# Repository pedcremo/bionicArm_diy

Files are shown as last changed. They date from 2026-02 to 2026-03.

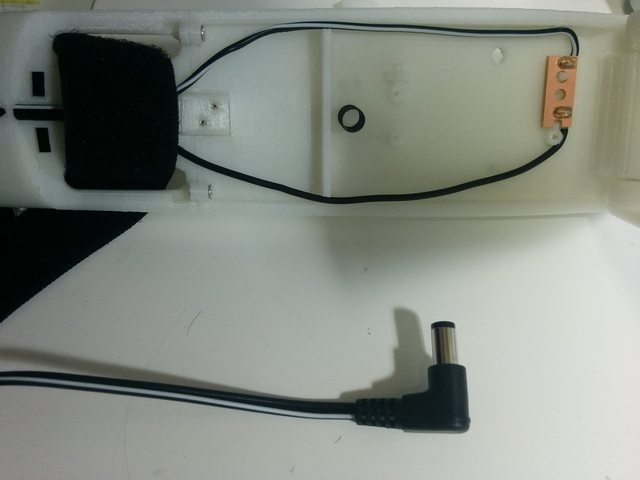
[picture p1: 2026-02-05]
HACKberry_original_project/HACKberry_circuit/BatteryBoard_v1/150908BatteryBoardTemp02.jpg

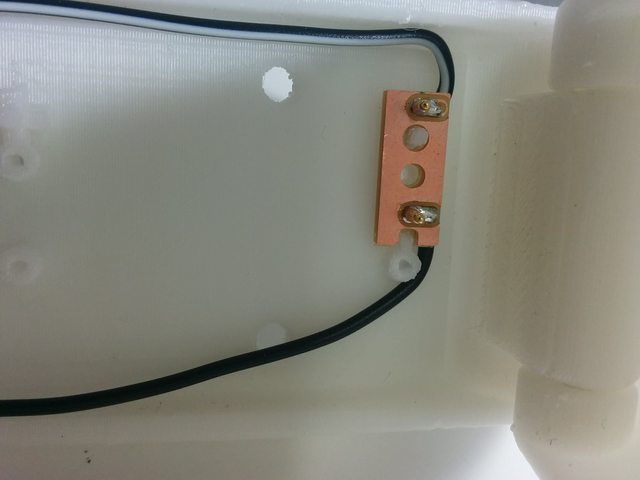
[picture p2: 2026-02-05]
HACKberry_original_project/HACKberry_circuit/BatteryBoard_v1/150908BatteryBoardTemp01.jpg

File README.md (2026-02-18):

At the moment we can explore two options. Brunel and hackberry arm. A britain and japanesse projects respectively. 
Brunel seems more a hand and it looks like more robust and handy. Moreover the company releasing their design sells commercial bionic orthoprotesic arms. 

# Brunel 2.0 hand openbionicslabs
In this repository the most promising device seems brunei hand 
https://github.com/Open-Bionics

# Hackberry arm
We want to upgrade HACKberry bionic arm to the next level. https://github.com/mission-arm/HACKberry

We want to use most of the 3D parts but redefining the sensoric, electronics and software used in the original project

# EMG sensors
More or equally important than hand is the signals produced by the sensors. Preferably EMG ones. We have several options. 
- https://wearables.com/products/myo
- https://psylink.me/
- https://www.btsbioengineering.com/products/freeemg/
- https://myoware.com/

# other options

https://hub.e-nable.org/s/e-nable-devices/wiki/Unlimbited+Arm+v2.1

In the meanwhile could be interesting to get a try in a pure mechanical open prothesic arm. Take a look at https://www.makerhand.com/

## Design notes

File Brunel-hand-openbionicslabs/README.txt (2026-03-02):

Brunel Hand 2.0 by openbionics on Thingiverse: 
https://www.thingiverse.com/thing:3000641

Summary:
The Brunel Hand 2.0 is an advanced, lightweight and precise 
robotic hand for researchers. With a low cost and open source 
design, this fully articulated device is primed to revolutionise
 the future of robotics research. All over the world, 
 university researchers and roboticists are using the Brunel 
 Hand 2.0. It has nine degrees of freedom, four degrees of 
 articulation, and can be programmed using the Arduino 
 programming environment.The Brunel Hand 2.0 is compatible with 
 robot arms and perfect for anyone doing a project with robotic 
 hands or wants a neat, light, and functional robotic hand for 
 use with a humanoid robot. 
 
 It's an excellent platform for 
 research into prosthetics, object grasping and many 
 human-robot-interaction applications.3D Printed Components:
 All of the components required for a right hand start with 'RH' 
 and the components for a left hand start with 'LH'. 
 Assembly instructions are available in 'Thing Files'.
 
 Non-3D Printed Components:
 
 1x - Chestnut PCB 
 https://openbionicslabs.com/shop/chestnut-board

 3x - PQ12 Motors 
 https://openbionicslabs.com/shop/pq12-63-12-p
 
 3x - Conical Springs 
 https://www.assocspring.co.uk/conical-springs/A0600-029-1250-S
 
 8x - Finger Extension Springs 
 http://www.flexosprings.com/search-products?sku=ac2305
 
 1x - Thumb Extension Spring 
 http://www.flexosprings.com/search-products?sku=AD2505
 
 11x - 3x10mm Dowel Pins 
 http://www.boneham.co.uk/Products/dowel-pins/metric-iso-8734b-parallel-dowel-pins
 
 2x - M2x5mm Torx Countersunk Screws 
 https://www.accu.co.uk/en/hexalobular-countersunk-screws/7537-SHK-M2-5-A4
 
 2x - M2x8mm Torx Countersunk Screws 
 https://www.accu.co.uk/en/hexalobular-countersunk-screws/7459-SHK-M2-8-A2
 
 15x M2x10mm Torx Countersunk Screws 
 https://www.accu.co.uk/en/hexalobular-countersunk-screws/7460-SHK-M2-10-A2
 
 6x - M2x16mm Torx Countersunk Screws 
 https://www.accu.co.uk/en/hexalobular-countersunk-screws/7462-SHK-M2-16-A2
 
 10x - M1.4x5mm Cap Head Screws 
 https://www.accu.co.uk/en/cap-head-screws/3774-SSCF-M1-4-5-A2
 
 5x - M2x5mm Slot Pan Machine Screw 
 https://www.pts-uk.com/products/machine_screws_large_head_slot_pan_machine_screws_metric_a2/a9210205
 
 1x - M3x10mm Winged Screw
 https://www.accu.co.uk/en/wing-screws/67276-SWI-M3-10-A2
 
 22x - M2 Brass Heatfit Inserts 
 https://www.insertsdirect.com/acatalog/unheaded-heatfit-insert.html
 
 1x - M3 Brass Heatfit Inserts 
 https://www.insertsdirect.com/acatalog/unheaded-heatfit-insert.html
 
 4x - Black Velvet Tendon 450mm 
 https://openbionicslabs.com/shop/tendon-line
 
 1x - 12V Power Cable 
 https://openbionicslabs.com/shop/12v-dc-power-supply
 
 1x - Micro USB Cable 
 https://www.lambda-tek.com/Cables-Direct-99CDL2-1601~sh/B6022916
 
 1x - VitaFlex 30 Urethane 
 https://www.benam.co.uk/products/urethane/vytaflex/
 
 1x - Ferrite Core 
 https://www.rapidonline.com/Catalogue/Product/26-2655
 
 This work is licensed under the Creative Commons Attribution-ShareAlike 4.0 
 International License.

 Amazon list 

 Electrónica y Actuadores

    1x - Chestnut PCB https://www.amazon.es/s%3Fk%3DTeensy%2B4.0

        Nota: Es una placa propietaria. Si no la encuentras, la alternativa estándar en prótesis biónicas es usar un Teensy 3.2 o 4.0 con un terminal shield.

        Alternativa: Teensy 4.0

    3x - PQ12 Motors (Actuonix)

        Enlace Amazon: Actuonix PQ12-P Linear Actuator 
        https://www.amazon.es/s?k=Actuonix+PQ12

    1x - 12V Power Cable (Fuente de alimentación)

        Enlace Amazon: Fuente Alimentación 12V 2A Jack 5.5mm

    1x - Micro USB Cable (Reforzado)

        Enlace Amazon: Cable Micro USB Trenzado

Resortes y Muelles (Springs)

    3x - Conical Springs / 8x Finger Springs

        Nota: Es mejor comprar un kit de surtido de muelles de acero inoxidable para encontrar la tensión exacta.

        Enlace Amazon: Kit de 200 muelles de tracción y compresión
        https://www.amazon.es/s?k=Actuonix+PQ12

Tornillería y Pasadores (Métrica 2 y 1.4)

He sustituido los Torx por Allen (Hexagonales) o Estrella (Phillips), ya que son mucho más fáciles de encontrar en Amazon y cumplen la misma función biónica.

    11x - 3x10mm Dowel Pins (Pasadores de acero)

        Enlace Amazon: Pasadores 3x10mm (50 unidades)
        https://www.amazon.es/dp/B08H4MB7N5

    Kit de Tornillos M2 (Cubre 5mm, 8mm, 10mm y 16mm)

        Es más económico comprar el maletín que las medidas sueltas.

        Enlace Amazon: Kit Tornillos M2 Cabeza Avellanada/Plana
        https://www.amazon.es/dp/B08H4MB7N5

    10x - M1.4x5mm Cap Head Screws

        Enlace Amazon: Micro Tornillos M1.4
        https://www.amazon.es/dp/B08H4MB7N5

    22x - M2 & 1x M3 Brass Heatfit Inserts (Insertos roscados para calor)

        Enlace Amazon: Kit Insertos de Latón M2 y M3
        https://www.google.com/search?q=https://www.amazon.es/dp/B08K1BVGN9

    Materiales de Construcción y Tendones

    4x - Black Velvet Tendon (Línea de Pesca de alta resistencia)

        Open Bionics usa hilo técnico, pero el estándar de reemplazo es hilo de pesca trenzado (Dyneema/Spectra) de 100lb, que es irrompible.

        Enlace Amazon: Hilo Trenzado 100lb (45kg)

    1x - VitaFlex 30 Urethane (Para las puntas de los dedos)

        Nota: Amazon no suele vender Smooth-On por políticas de químicos, pero esta silicona de duplicado es idéntica en dureza (Shore 30).

        Enlace Amazon: Silicona de Condensación Shore A30

    1x - Ferrite Core (Filtro de ruido)

        Enlace Amazon: Clip de Ferrita para cables (10 unidades)

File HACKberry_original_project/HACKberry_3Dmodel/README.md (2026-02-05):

## Folder Structure & File Types

Here is the purpose of each folder included in this project and when you should use it.

### 1. STL Folder (For 3D Printing)
* **What it is:** The universal standard for 3D printing. `.stl` files are "mesh" files made of millions of tiny triangles.
* **Purpose:** Use this if you want to **3D print** the object.
* **Pros/Cons:** It is lightweight and universally accepted by 3D printer software (slicers). However, it is very difficult to edit because it lacks "smart" geometry (it's just a hollow shell).

### 2. STEP Folder (For CAD & Precision Editing)
* **What it is:** The professional standard for sharing solid models between different CAD programs (like SolidWorks, Fusion 360, Rhino, or FreeCAD).
* **Purpose:** Use this if you need to **modify the dimensions** or **CNC machine** the part.
* **Pros/Cons:** Unlike STL, this format understands "true" geometry (perfect circles, smooth curves, solid volume). It is the best format for engineering work but does not contain the design history (timeline).

### 3. F3Z Folder (For Autodesk Fusion 360 Users)
* **What it is:** A native archive file specifically for **Autodesk Fusion 360**. It contains the main design file plus any linked components or sub-assemblies.
* **Purpose:** Use this only if you use Fusion 360 and want to **see the full design history**.
* **Pros/Cons:** It preserves the "timeline," meaning you can roll back time to see how the object was built and change the original sketches. It is useless if you do not use Fusion 360.

### 4. Polygon Folder (For Animation, VR & Rendering)
* **What it is:** This contains formats like `.OBJ`, `.FBX`, or `.PLY`. These are mesh files similar to STLs but usually support textures, colors, and UV maps.
* **Purpose:** Use this if you are using artistic software like **Blender, Maya, 3ds Max, or Unity/Unreal Engine**.
* **Pros/Cons:** Ideal for making renders, animations, or video game assets. It is generally not suitable for precision manufacturing or CAD engineering.

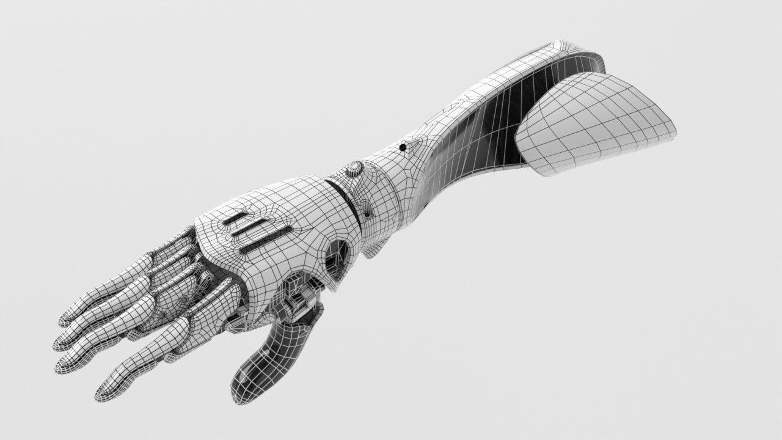
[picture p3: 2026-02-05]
HACKberry_original_project/HACKberry_3Dmodel/Polygon/29000_polygons/29000_polygons.jpg

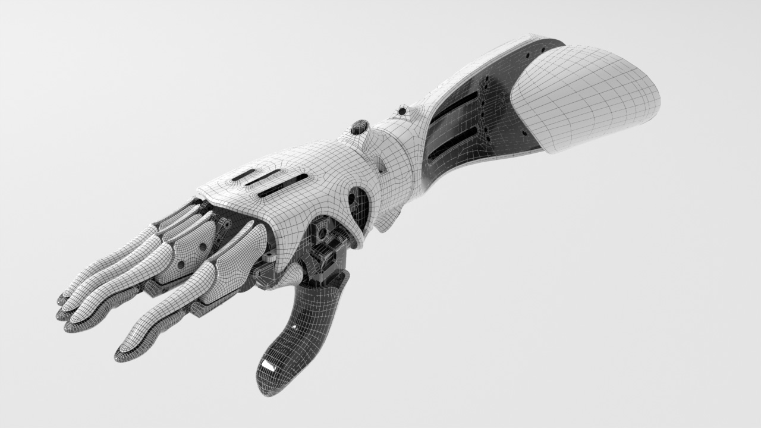
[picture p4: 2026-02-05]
HACKberry_original_project/HACKberry_3Dmodel/Polygon/77000_polygons/77000_polygons.jpg

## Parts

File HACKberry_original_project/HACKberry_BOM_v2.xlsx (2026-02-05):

Unit | Part Name | Description | Quantity | US delivery | US substitution | JP delivery | JP substitution
Hand | R-H-01.stl (or L-H-01.stl) | 3D print part (old name: HbWristMount01.stl) | 1
 | R-H-02.stl (or L-H-02.stl) | 3D print part (old name: HbPalmBase03.stl) | 1
 | R-H-03.stl (or L-H-03.stl) | 3D print part (old name: HbShaftStopperB04.stl) | 1
 | R-H-04.stl (or L-H-04.stl) | 3D print part (old name: HbShaftStopperA04.stl) | 1
 | R-H-05.stl (or L-H-05.stl) | 3D print part (old name: HbRing-LittleCouplerLink01.stl) | 1
 | R-H-06.stl (or L-H-06.stl) | 3D print part (old name: HbMiddle-RingCouplerLink01.stl) | 1
 | R-H-07.stl (or L-H-07.stl) | 3D print part (old name: HbFingerMainCouplerLink01.stl) | 1
 | R-H-08.stl (or L-H-08.stl) | 3D print part (old name: HbIndexMotorGear02.stl) | 1
 | R-H-09.stl (or L-H-09.stl) | 3D print part (old name: HbMotorHolder01.stl) | 1
 | R-H-10.stl (or L-H-10.stl) | 3D print part (old name: HbMaxButton05.stl) | 1
 | R-H-11.stl (or L-H-11.stl) | 3D print part (old name: HbMinButton05.stl) | 1
 | R-H-12.stl (or L-H-12.stl) | 3D print part (old name: HbThumbButton05.stl) | 1
 | R-H-13.stl (or L-H-13.stl) | 3D print part (old name: HbFingerLockButton05.stl) | 1
 | R-H-14.stl (or L-H-14.stl) | 3D print part (old name: HbPowerLever05.stl) | 1
 | R-H-15.stl (or L-H-15.stl) | 3D print part (old name: HbBackCover02.stl) | 1
Socket | R-SO-01.stl (or L-SO-01.stl) | 3D print part (old name: HbMainFrameB01.stl) | 1
 | R-SO-02.stl (or L-SO-02.stl) | 3D print part (old name: HbMainFrameA01.stl) | 1
 | R-SO-03.stl (or L-SO-03.stl) | 3D print part (old name: HbBatteryLockKnob01.stl) | 1
 | R-SO-04.stl (or L-SO-04.stl) | 3D print part (old name: HbBatteryCase01.stl) | 1
 | R-SO-05.stl (or L-SO-05.stl) | 3D print part (old name: HbBatteryDoorKnob03.stl) | 1
 | R-SO-06.stl (or L-SO-06.stl) | 3D print part (old name: HbBatteryDoorLever03.stl) | 1
 | R-SO-07.stl (or L-SO-07.stl) | 3D print part (old name: HbBatteryDoor03.stl) | 1
 | R-SO-08.stl (or L-SO-08.stl) | 3D print part (old name: HbBatteryHingeA03.stl) | 1
 | R-SO-09.stl (or L-SO-09.stl) | 3D print part (old name: HbBatteryHingeB03.stl) | 1
 | R-SO-10.stl (or L-SO-10.stl) | 3D print part (old name: HbBatteryHingeC03.stl) | 1
Index Finger | R-I-01.stl (or L-I-01.stl) | 3D print part (old name: HbIndexMiddle-DistalPhalanx02.stl) | 1
 | R-I-02.stl (or L-I-02.stl) | 3D print part (old name: HbIndexCouplerLinkCover02.stl) | 1
 | R-I-03.stl (or L-I-03.stl) | 3D print part (old name: HbIndexInputLink02.stl) | 1
 | R-I-04.stl (or L-I-04.stl) | 3D print part (old name: HbIndexCouplerLink02.stl) | 1
 | R-I-05.stl (or L-I-05.stl) | 3D print part (old name: HbIndexReleaseLever02.stl) | 1
 | R-I-06.stl (or L-I-06.stl) | 3D print part (old name: HbIndexProximalPhalanx03.stl) | 1
 | R-I-07.stl (or L-I-07.stl) | 3D print part (old name: HbIndexProximalPhalanxCover02.stl) | 1
Middle,Ring,Little Finger | R-O-01.stl (or L-O-01.stl) | 3D print part (old name: HbMiddle-DistalPhalanx02.stl) | 3
 | R-O-02.stl (or L-O-02.stl) | 3D print part (old name: HbCouplerLinkCover03.stl) | 3
 | R-O-03.stl (or L-O-03.stl) | 3D print part (old name: HbProximalPhalanx02.stl) | 3
 | R-O-04.stl (or L-O-04.stl) | 3D print part (old name: HbProximalPhalanxCover02.stl) | 3
 | R-O-05.stl (or L-O-05.stl) | 3D print part (old name: HbCouplerLink02.stl) | 3
Sensor | C-SE-01.stl | 3D print part (old name: HbSensorHolder02.stl) | 1
 | C-SE-02.stl | 3D print part (old name: HbSensorPlate01.stl) | 1
External Battery | C-B-01.stl | 3D print part (old name: HbBatteryCaseHolder01.stl) | 1
 | C-B-02.stl | 3D print part (old name: HbBatteryLockKnob01.stl) | 1
 | C-B-03.stl | 3D print part (old name: HbBatteryCase01.stl) | 1
Thumb | R-T-01.stl (or L-T-01.stl) | 3D print part (old name: HbThumbProximalPhalanx02.stl) | 1
 | R-T-02.stl (or L-T-02.stl) | 3D print part (old name: HbThumbProximalPhalanxBase02.stl) | 1
 | R-T-03.stl (or L-T-03.stl) | 3D print part (old name: HbThumbMetacarpalPhalanx02.stl) | 1
 | R-T-04.stl (or L-T-04.stl) | 3D print part (old name: HbThumbLockButton01.stl) | 1
 | R-T-05.stl (or L-T-05.stl) | 3D print part (old name: HbThumbJointHolder01.stl) | 1
 | R-T-06.stl (or L-T-06.stl) | 3D print part (old name: HbThumbMetacarpalPhalanxCover02.stl) | 1
Wrist | R-W-01.stl (or L-W-01.stl) | 3D print part (old name: HBabductionLever02.stl) | 1
 | R-W-02.stl (or L-W-02.stl) | 3D print part (old name: HBarmMountBase03.stl) | 1
 | R-W-03.stl (or L-W-03.stl) | 3D print part (old name: HBpronationLockPin02.stl) | 1
 | R-W-04.stl (or L-W-04.stl) | 3D print part (old name: HBWristLockplate.stl) | 1
 | R-W-05.stl (or L-W-05.stl) | 3D print part (old name: HBlockPlateHolder02.stl) | 1
 | R-W-06.stl (or L-W-06.stl) | 3D print part (old name: HBejectorLever02.stl) | 1
 | R-W-07.stl (or L-W-07.stl) | 3D print part (old name: HbArmMountU01.stl) | 1
 | R-W-08.stl (or L-W-08.stl) | 3D print part (old name: HBarmMountBaseCover03.stl) | 1
Hand | DMW-BLF19 | Battery and Charger | 1 | Amazon.com (http://www.amazon.com/dp/B00AKHJSTW) | Amazon.com (http://www.amazon.com/dp/B00MP3MX7I/) | Amazon.jp (http://www.amazon.co.jp/dp/B009WPY97Y) | Yahoo (https://store.shopping.yahoo.co.jp/batteryginnkouhkr/10000508.html)
 | CP 0.5-6-8 | Coil spring -Material diameter:0.5 -Outside diameter:6 -Free height:8 -Active coil turns:3 | 6 |  | Lee Spring [LCM050C 02 M] *haven't tested yet (http://www.leespring.com/product_spec.asp?partnum=LCM050C02M&springType=C&subType=) | sotec (http://sotec-bane.jp/search/try/compression/keyword/CP%200.5-6-8/)
 | TS 0.4-3.2-14 (This part is only used for SocketU02) | Tension spring -Material diameter:0.4 -Outside diameter:3.2 -Free length:14 | 1 |  | Lee Spring [LE 014A 02 S] *haven't tested yet (http://www.leespring.com/product_spec.asp?partnum=LE014A02S&springType=E&subType=) | sotec (http://sotec-bane.jp/search/try/tension/keyword/TS%200.4-3.2-14/)
 | TOS 0.3-4-270-5 | Torsion spring -Material diameter:0.3 -Inside diameter:4 -Free Angle:270 -Active coil turns:5 -Arm length:12 | 1 |  | Lee Spring [LTL012A 05 M] *haven't tested yet (http://www.leespring.com/product_spec.asp?partnum=LTL012A05M&springType=T&subType=) | sotec (http://sotec-bane.jp/search/try/torsion/field/material_code/S/)
 | SBI-SUJ-1d4 | Steel ball -Spherical diameter:1/4" | 2 | Amazon.com (http://www.amazon.com/dp/B007B2AHM6/) |  | Amazon.jp (http://www.amazon.co.jp/dp/B00HXXHJMY/)
 | flatScrewM2L6PHI3.3T1.3 | Flat head tapping screw -Shaft diameter:2 -Head diameter:3.3 -Length:6 | 25 |  |  | wilco (http://wilco.jp/products/F/FBF-N.html)
 | ScrewM3L8Btite | Tapping screw -Shaft diameter:3 -Head diameter:5.5 -Length:8 | 6 |  |  | wilco (http://wilco.jp/products/F/FBP-EB.html)
 | ES08MD | Servo motor(small) | 2 | Emax (http://www.emaxmodel.com/servos/servos/es08md.html) | Emax (http://www.emaxmodel.com/servos/servos/es08ma-ii.html) | KK HOBBY (http://www.kkhobby.com/SHOP/SV070.html) | Emax (http://www.emaxmodel.com/servos/servos/es08ma-ii.html)
 | HD3001HB | Servo motor(large) | 1 | rcMarT (http://www.rcmart.com/power-high-speed-analog-servo-touring-drift-hd3001hb-p-63124.html?cPath=1099_50) |  | rcMarT (http://www.rcmart.com/power-high-speed-analog-servo-touring-drift-hd3001hb-p-63124.html?cPath=1099_50) | Akizuki (http://akizukidenshi.com/catalog/g/gM-01793/)
 | RXEF050 | Resettable Fuses | 2 | Mouser (http://www.mouser.jp/search/ProductDetail.aspx?R=0virtualkey0virtualkeyRXEF050) |  | Akizuki (http://akizukidenshi.com/catalog/g/gP-01355/)
 | RXEF040 | Resettable Fuses | 1 | Mouser (http://www.mouser.jp/search/ProductDetail.aspx?R=0virtualkey0virtualkeyRXEF040) |  | Akizuki (http://akizukidenshi.com/catalog/g/gP-00776/)
 | UsmBearing | Bearing -Bore diameter:4 -Outside diameter -Width | 1 | spbusa (http://spbusa.thomasnet.com/item/metric-series/flanged-shielded-metric-bearings/mf74zz) |  | KMT (http://www.kmt-online.com/shopdetail/065000000002/)
 | ScrewM2L10 | Tapping screw -Shaft diameter:2 -Head diameter:3.5 -Length:10 | 46 |  |  | wilco (http://wilco.jp/products/F/FBP-EB.html)
 | MetalCollar | Spacer -Inside diameter:2.2 -Outside diameter:3.2 -Length:5 | 6 | Hirosugi-Keiki(CU-2005PH) (http://www.hirosugi.jp/products/U/CU-PH.html) |  | wilco(CU-2005PH) (http://wilco.jp/products/U/CU-PH.html)
 | WasherM2Ph4.3T0.3 | Washer -Inside diameter:2.3 -Outside diameter:4.3 -Thickness:0.3 | 5 |  |  | wilco (http://wilco.jp/products/U/UW.html)
 | Shaft d2L10 (in 3d data, it is named as HbFingerPosture01) | Shaft -Diameter:2 -Length:10 | 10 | Hirosugi-Keiki(SRU-2010) (http://www.hirosugi.jp/products/U/SRU-0000.html) |  | wilco(SRU-2010) (http://wilco.jp/products/U/SRU-2000.html)
 | Shaft d2L15 (in 3d data, it is named as HbFingerPosture01) | Shaft -Diameter:2 -Length:15 | 7 | Hirosugi-Keiki(SRU-2015) (http://www.hirosugi.jp/products/U/SRU-0000.html) |  | wilco(SRU-2015) (http://wilco.jp/products/U/SRU-2000.html)
BatteryBoard V1 | HbBatteryPcb01 | PCB | 1 | NA |  | NA
 | MC2374L | DC Plug | 1 |  | mouser (http://www.mouser.jp/ProductDetail/Schurter/48405201/?qs=sGAEpiMZZMv1TUPJeFpwblPOHWNGLddK41OskmiMORc%3d) | momohara (http://www.mepc.jp/store/index.php?main_page=product_info&cPath=48&products_id=34171)
 | 101050-003 | Batt Contact probe | 2 | Mouser (http://www.mouser.com/ProductDetail/IDI/101050-003/) |  | Mouser (http://www.mouser.jp/search/ProductDetail.aspx?R=0virtualkey0virtualkey101050-003) | CSL (https://connectorsolutions.co.uk/probes/battery-and-connector-probes/101050/)
HandBoard Mk1 | ArduinoMicroShieldBoard01 | PCB | 1 | NA |  | NA
 | DC-DCconveerter | Adjustable DC/DC Power Converter (1.25-35V/3A) | 1 | SeeedStudio (https://www.seeedstudio.com/adjustable-dcdc-power-converter-125v-35v3a-p-1534.html) |  | Sengoku (https://www.sengoku.co.jp/mod/sgk_cart/detail.php?code=EEHD-4RR8)
 | Arduino Micro |  | 1 | Adafruit (http://www.adafruit.com/product/1086) |  | SWITCHSCIENCE (https://www.switch-science.com/catalog/1120/)
 | MJ-4535-3 | 3-Conductor miniture jack for PCB stereo | 1 |  |  | Sengoku (https://www.sengoku.co.jp/mod/sgk_cart/detail.php?code=EEHD-4HDZ)
 | Pin Socket | 2.54mm Female Header 1x22 | 1 | Pololu (https://www.pololu.com/product/1020) |  | Akizuki (http://akizukidenshi.com/catalog/g/gC-05779/)
 | Pin Header | 2.54mm male Header 1x3 | 3 | Pololu (https://www.pololu.com/product/965) |  | Akizuki (http://akizukidenshi.com/catalog/g/gC-06192/)
 | MJ179PH | DC Jack | 1 | Octpart (https://octopart.com/mj-179ph-multicomp-11351490) |  | momohara (http://www.mepc.jp/store/index.php?main_page=product_info&products_id=46428)
 | SKRGAQD010 | Tace Switch | 4 | mouser (http://www.mouser.com/ProductDetail/ALPS/SKRGAQD010/) |  | ALPS (https://www4.alps.co.jp/densokunou/seriesDetails/;jsessionid=84ED12CFFFB0C3AF1BAB9E00D2A4C632?productId=1&varietyId=3&seriesId=61)
 | SS-12SDP2 | Slide Switch | 1 |  |  | marutu (http://www.marutsu.co.jp/pc/i/14846/)
 |  | Lead Wire Cable 90mm | 2
 |  | Lead Wire Cable 50mm | 2
Sensor Unit | HbSensorBoard01 | PCB | 1 | NA |  | NA
 | ST-PJ-312 | SMD Audio jack;3.5mm | 1 | Seeed (Please search 320040007 in the link and you will find it.) (https://www.seeedstudio.com/opl.html)
 | QRE1113GR | Photo Reflector | 1 | Mouser (http://www.mouser.com/ProductDetail/Fairchild-Semiconductor/QRE1113GR/) |  | Mouser (http://www.mouser.com/ProductDetail/Fairchild-Semiconductor/QRE1113GR/)
 | RC0603JR-07100RL | SMD Resister 100Ω | 1 | Seeed (Please search 301010090 in the link and you will find it.) (https://www.seeedstudio.com/opl.html)
 | RC0603JR-0710KL | SMD Resister 10kΩ | 1 | Seeed (Please search 301010004 in the link and you will find it.) (https://www.seeedstudio.com/opl.html)
 | P312-001-RA | Mini Stereo Audio Cable | 1 | Amazon (http://www.amazon.com/dp/B00M5FKFB2/) |  | Amazon (https://www.amazon.co.jp/gp/product/B008PMG5GI/ref=oh_aui_detailpage_o00_s00?ie=UTF8&psc=1) | Amazon (http://www.amazon.co.jp/gp/product/B00B1ZKV7U)
 | Vercro strap | Vercro strap | 1 | Amazon (http://www.amazon.com/dp/B011NO1Z28) |  | Amazon (http://www.amazon.co.jp/dp/B01CQXGKKM/)
 | Sensor Cushion | Sensor Cushion | 1 | NA |  | NA

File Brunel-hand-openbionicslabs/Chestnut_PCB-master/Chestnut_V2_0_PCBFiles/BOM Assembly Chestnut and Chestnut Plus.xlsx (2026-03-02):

Qty | Value | Device | Package | Parts | Description | Chestnut Fit | Chestnut Plus Fit | Manufacturer Part No. | Supplier | Link | Cost / 100 | Cost Per Unit Chestnut | Cost Per Unit Chestnut +
2 | DNF | HEADER-1X1ROUND | 1X01_ROUND | 3.3V, GND | PIN HEADER | N | N | N/A | N/A | N/A | 0 | 0 | 0
8 | 10nF | C-EUC0402 | C0402 | C1, C16, C19, C30, C36, C37, C38, C52 | CAPACITOR, European symbol | Y | Y | GRM155R71E103KA01D | Mouser | http://www.mouser.co.uk/ProductDetail/Murata/GRM155R71E103KA01D/ | £0.003 | 0.024 | 0.024
1 | 22uF | C-EUC1210 | C1210 | C12 | CAPACITOR, European symbol | Y | Y | GRM32ER61E226KE15L | Mouser | http://www.mouser.co.uk/ProductDetail/Murata/GRM32ER61E226KE15L/ | £0.18 | 0.183 | 0.183
2 | 2.2uF | C-EUC0603 | C0603 | C15, C18 | CAPACITOR, European symbol | Y | Y | GRM188R71A225KE15D (http://uk.farnell.com/murata/grm188r71a225ke15d/cap-mlcc-x7r-2-2uf-10v-0603/dp/1797012) | Mouser | http://www.mouser.co.uk/ProductDetail/Murata/GRM188R71A225KE15D/ | £0.09 | 0.174 | 0.174
9 | 10uF | C-EUC0805 | C0805 | C2, C4, C7, C10, C13, C22, C33, C34, C53 | CAPACITOR, European symbol | Y | Y | GRM21BR61E106KA73L | Mouser | http://www.mouser.co.uk/ProductDetail/Murata/GRM21BR61E106KA73L/ | £0.04 | 0.333 | 0.333
2 | 22pF | C-EUC0402 | C0402 | C26, C27 | CAPACITOR, European symbol | Y | Y | 04025A220JAT2A | Mouser | http://www.mouser.co.uk/ProductDetail/AVX/04025A220JAT2A/ | £0.02 | 0.048 | 0.048
20 | 100nF | C-EUC0402 | C0402 | C3, C5, C6, C8, C9, C11, C14, C17, C20, C21, C23, C24, C25, C28, C29, C31, C35, C48, C50, C51 | CAPACITOR, European symbol | Y | Y | CGA2B3X7R1H104K050BB | Mouser | http://www.mouser.co.uk/ProductDetail/TDK/CGA2B3X7R1H104K050BB/ | £0.03 | 0.64 | 0.64
1 | 4.7uF | C-EUC0603 | C0603 | C32 | CAPACITOR, European symbol | Y | Y | GRM188R6YA475KE15D | Mouser | http://www.mouser.co.uk/ProductDetail/Murata/GRM188R6YA475KE15D/ | £0.07 | 0.071 | 0.071
2 | 10pF | C-EUC0402 | C0402 | C40, C41 | CAPACITOR, European symbol | Y | Y | GRM1555C1H100JA01D | Mouser | http://www.mouser.co.uk/ProductDetail/Murata/GRM1555C1H100JA01D/ | £0.003 | 0.006 | 0.006
1 | ManNum: 694106106102 | DCBARRELSMT | DCJACK_2MM_SMT | CN1 | 2.0mm DC Barrel Jack | Y | Y | Wurth 694106106102 | Mouser | http://www.mouser.co.uk/ProductDetail/Wurth-Electronics/694106106102/ | £0.92 | 0.922 | 0.922
1 | CD1206-S01575 | 0012_CD1206-S01575 | MINIMELF | D1 | small-signal high-speed Switching Diodes CD1206 | Y | Y | CD1206-S01575 | Mouser | http://www.mouser.co.uk/ProductDetail/Bourns/CD1206-S01575/ | £0.04 | 0.04 | 0.04
1 | 0805L100WR | FUSE_PTC-0805 | PTC0805 | F2 | Resettable PTC | Y | Y | 0805L100WR | Farnell | http://uk.farnell.com/littelfuse/0805l100wr/resettable-fuse-0805-6v-1a/dp/1832106 | £0.86 | 0.86 | 0.86
1 | MCF0805B2R00FSTR | FUSE_PTC-0805 | PTC0805 | F3 | Resettable PTC | Y | Y | MCF0805B2R00FSTR | Farnell | http://uk.farnell.com/multicomp/mcf0805b2r00fstr/fuse-smd-0805-2a/dp/1337421RL | £0.41 | 0.407 | 0.407
1 | SAMD21G18A-AUT | INTEGRATEDCIRCUITS_1792_SAMD21G18A-AUT | INTEGRATEDCIRCUITS_TQFP48-7X7 | IC2 | Atmel D21 32bit ARM Cortex-M0 microcontroller - 48 PIN | Y | Y | ATSAMD21G18A-AUT | Mouser | http://www.mouser.co.uk/ProductDetail/Atmel/ATSAMD21G18A-AUT/ | £2.88 | 2.88 | 2.88
1 | CON_HEADER_1X08-PTH | CON_HEADER_1X08-PTH | M1X8 | J1 |  | N | N | N/A | N/A | N/A | 0 | 0 | 0
1 | L1812 - 3.3uH - 1800403RL | INDUCTOR-L1812 | L1812 | L1 | Inductor | Y | Y | 744045003 | Mouser | http://www.mouser.co.uk/ProductDetail/Wurth-Electronics/744045003/ | £0.47 | 0.471 | 0.471
1 | MH2029-300Y | 0001_BLM21PG300SN1D_/_MH2029-300Y | 805 | L2 | BLM21 | Y | Y | MH2029-300Y | Mouser | http://www.mouser.co.uk/ProductDetail/Bourns/MH2029-300Y/ | £0.03 | 0.028 | 0.028
1 |  | LED0603 | CHIPLED_0603 | LED1 | LED | Y | Y | LG Q396-PS-35 | Mouser | http://www.mouser.co.uk/ProductDetail/OSRAM-Opto-Semiconductors/LG-Q396-PS-35/ | £0.08 | 0.076 | 0.076
1 | WS2812B3535 | WS2812B3535 | LED3535 | LED2 |  | Y | Y | WS2812B3535 | DigiKey | https://www.digikey.co.uk/product-detail/en/adafruit-industries-llc/2659/1528-1542-ND/5804108 | £0.33 | 0.33 | 0.33
4 | SFW5R-1STE1LF | SFW5R-1STE1LF | FCI_SFW5R-1STE1LF | M1, M2, M3, M4 | FFC/FPC CONNECTOR, RECEPTACLE, 5POS 1ROW | Y | Y | SFW5R-1STE1LF | Mouser | http://www.mouser.co.uk/ProductDetail/FCI-Amphenol/SFW5R-1STE1LF/ | £0.37 | 1.472 | 1.472
1 | 62.5K | R-EU_R0603 | R0603 | R1 | RESISTOR, European symbol | Y | Y | CRCW0603100KFKEA | Mouser | http://www.mouser.co.uk/ProductDetail/Vishay-Dale/CRCW0603100KFKEA/ | £0.02 | 0.019 | 0.019
4 | 0.47R | R-EU_R0805 | R0805 | R14, R17, R19, R26 | RESISTOR, European symbol | Y | Y | RL0805FR-7W0R47L | Mouser | http://www.mouser.co.uk/ProductDetail/Yageo/RL0805FR-7W0R47L/ | £0.06 | 0.248 | 0.248
1 | 330R | R-EU_R0402 | R0402 | R15 | RESISTOR, European symbol | Y | Y | RC0402FR-07330RL | Mouser | http://www.mouser.co.uk/ProductDetail/Yageo/RC0402FR-07330RL/ | £0.002 | 0.002 | 0.002
1 | 20K | R-EU_R0603 | R0603 | R2 | RESISTOR, European symbol | Y | Y | CRCW060319K1FKEA | Mouser | http://www.mouser.co.uk/ProductDetail/Vishay/CRCW060319K1FKEA/ | £0.02 | 0.019 | 0.019
2 | 27R | R-EU_R0402 | R0402 | R21, R22 | RESISTOR, European symbol | Y | Y | RC0402JR-0727RL | Mouser | http://www.mouser.co.uk/ProductDetail/Yageo/RC0402JR-0727RL/ | £0.002 | 0.004 | 0.004
1 | DNF | R-EU_R0402 | R0402 | R28 | RESISTOR, European symbol | N | N | N/A | N/A | N/A | 0 | 0 | 0
9 | 10K | R-EU_R0402 | R0402 | R3, R4, R5, R6, R13, R16, R23, R24, R25 | RESISTOR, European symbol | Y | Y | CRCW040210K0FKED | Mouser | http://www.mouser.co.uk/ProductDetail/Vishay-Dale/CRCW040210K0FKED/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 | £0.02 | 0.171 | 0.171
4 | 27K | R-EU_R0402 | R0402 | R47, R48, R49, R50 | RESISTOR, European symbol | Y | Y | CRCW040227K0FKED | Mouser | http://www.mouser.co.uk/ProductDetail/Vishay-Dale/CRCW040227K0FKED/ | £0.02 | 0.076 | 0.076
12 | 1K | R-EU_R0402 | R0402 | R7, R8, R9, R29, R37, R39, R42, R46, R56, R57, R58, R10 | RESISTOR, European symbol | Y | Y | RC0402JR-071KL | Mouser | http://www.mouser.co.uk/ProductDetail/Yageo/RC0402JR-071KL/ | £0.002 | 0.024 | 0.024
6 | PTR1TP11R | PTR1TP11R | TP11R | TP1, TP2, TP3, TP4, TP5, TP6 | TEST PIN | N | N | N/A | N/A | N/A | 0 | 0 | 0
1 | TSZ124IQ4T | TSZ124IQ4T | TSZ124IQ4T | U$15 |  | N | Y | TSZ124IQ4T | Mouser | http://www.mouser.co.uk/ProductDetail/STMicroelectronics/TSZ124IQ4T/ | £1.40 | 0 | 1.4
1 | DLW5BTN501SQ2L | DLW5BTN501SQ2L | DLW5BTN501SQ2L | U$5 |  | Y | Y | DLW5BTN501SQ2L | Mouser | http://www.mouser.co.uk/ProductDetail/Murata/DLW5BTN501SQ2L/ | £0.54 | 0.539 | 0.539
1 | 24AA08T-I/OT | 24AA08T-I/OT | SOT95P290X145-5N | U$6 | 8K I2C Serial EEPROM | Y | Y | 24AA08T-I/OT | Mouser | http://www.mouser.co.uk/ProductDetail/Microchip/24AA08T-I-OT/ | £0.17 | 0.175 | 0.175
1 | LUMBERG_1503-13-VP3 | LUMBERG_1503-13-VP3 | LUMBERG_1503-13-VP3 | U$7 |  | Y | Y | 1503 13 VP3 | Farnell | http://uk.farnell.com/lumberg/1503-13-vp3/socket-3-5mm-jack-smt-4way/dp/1368640?ost=LUMBERG_1503-13-VP3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 | £0.71 | 0.714 | 0.714
4 | 101X14N330MV4T_X2Y_0603 | 101X14N330MV4T_X2Y_0603 | 101X14N330MV4T_X2Y_0603 | U$8, U$9, U$10, U$19 |  | Y | Y | 500X14W103MV4T | Mouser | http://www.mouser.co.uk/ProductDetail/Johanson/500X14W103MV4T/ | £0.09 | 0.364 | 0.364
1 | ST1S10PUR | ST1S10PUR | DFN400X400X100-9N | U1 | BUCK, 2.5-18V, 900KHZ, 3A, 0.8V, 8DFN | Y | Y | ST1S10PUR | Mouser | http://www.mouser.co.uk/ProductDetail/STMicroelectronics/ST1S10PUR/ | £0.93 | 0.93 | 0.93
2 | DRV8833RTYT | DRV8833RTYT | QFN65P400X400X80-17N | U2, U3 | DUAL H-BRIDGE MOTOR DRIVER,QFN-16 | Y | Y | DRV8833RTYT | Mouser | http://www.mouser.co.uk/ProductDetail/Texas-Instruments/DRV8833RTYT/ | £1.41 | 2.82 | 2.82
1 | NX3L2467PW | NX3L2467PW | SOP65P640X110-16N | U4 | Dual low-ohmic double-pole double-throw analog switch,T | Y | Y | NX3L2467PW,118 | Mouser | http://www.mouser.co.uk/ProductDetail/NXP/NX3L2467PW118/ | £0.28 | 0.285 | 0.285
1 | LSM9DS1 | LSM9DS1 | LGA24-8X4 | U5 | LSM9DS1 3D accelerometer, gyroscope & magnetometer | N | Y | LSM9DS1TR | Mouser | http://www.mouser.co.uk/ProductDetail/STMicroelectronics/LSM9DS1TR/ | £3.26 | 0 | 3.26
1 | CON-USB-F-MICRO-B | CON-USB-F-MICRO-B | CONN_USB_MICRO-B | USB1 | USB Female connector | Y | Y | 10104110-0001LF | Mouser | http://www.mouser.co.uk/ProductDetail/FCI/10104110-0001LF/ | £0.37 | 0.37 | 0.37
1 | 32,768Khz_SMD | 0213_ABS07-32.768KHZ-T | RESONATOR_EPSON_FC_145 | Y1 | 32,768KHz - SMD | Y | Y | ABS07-32.768KHZ-T | Mouser | http://www.mouser.co.uk/ProductDetail/ABRACON/ABS07-32768KHZ-T/ | £0.26 | 0.264 | 0.264
5 | CG0603MLC-05E | VARISTORCN0603 | CT/CN0603 | Z1, Z2, Z3, Z4, Z5 | VARISTOR | Y | Y | CG0603MLC-05E | Mouser | http://www.mouser.co.uk/ProductDetail/Bourns/CG0603MLC-05E/ | £0.11 | 0.55 | 0.55
 |  |  |  |  |  |  |  |  |  |  | Total | 16.539 | 21.199

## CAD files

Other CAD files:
Brunel-hand-openbionicslabs/3D_parts/Release STL's/Moulds/Thumb Mould/Left Hand/LH Thumb Mould (Main Body).stl
Brunel-hand-openbionicslabs/3D_parts/Release STL's/Moulds/Thumb Mould/Right Hand/RH Thumb Mould (Main Body).stl
Brunel-hand-openbionicslabs/3D_parts/Release STL's/Moulds/Palm Mould/Left Hand/LH Palm Mould (Main Body).stl
Brunel-hand-openbionicslabs/3D_parts/Release STL's/Moulds/Finger Mould/Brunel Finger Mould (Main Body).stl
Brunel-hand-openbionicslabs/3D_parts/Release STL's/Moulds/Palm Mould/Right Hand/RH Palm Mould (Main Body).stl
Brunel-hand-openbionicslabs/3D_parts/BlenderFiles/RightHand/Brunel Tendon Termination Jig/Meshes/BOOLEAN_Palm_and_Back_Cover_Divide.stl
Brunel-hand-openbionicslabs/3D_parts/BlenderFiles/RightHand/BrunelPose/Meshes/IPJd_002.stl
Brunel-hand-openbionicslabs/3D_parts/BlenderFiles/RightHand/BrunelRightFinger/Meshes/ID_002.stl
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

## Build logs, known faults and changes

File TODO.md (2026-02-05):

## Translation
- Translate the tutorial (handbook) from Japanese to English, Spanish, and Catalan.

## Research and exploration
- Investigate ways to improve the current proposed sensory, electronics, and software components. Ideas:
  - Use something like the Myo armband to capture EMG activity around arm muscles: https://wearables.com/products/myo
  - Consider an open hardware/software alternative to the Myo armband: https://psylink.me/

- In the meanwhile could be interesting to get a try in a pure mechanical open prothesic arm. Take a look at https://www.makerhand.com/

## PCB improvements
- OTA upgradability.
- Bluetooth support, at least for the initial training phase.
- FreeRTOS-capable; we want minimal user delay.
- Explore edge inference capabilities.

## Software improvements
- Android/iOS app for initial training and adjustment of the sensory band and device.
- Real C programming with FreeRTOS.

## Prototype manufacturing
- PCBs and electronics assembly: https://jlcpcb.com/
- 3D printing with durable materials: https://jlc3dp.com/

## Mapping atmega328p to nodeMCU

Function,ATmega Pin,NodeMCU Pin,NodeMCU GPIO,Notes / Constraints
I2C SDA,A4,D2,GPIO 4,Mandatory for ADC/Display
I2C SCL,A5,D1,GPIO 5,Mandatory for ADC/Display
Serial RX,D0,RX,GPIO 3,Used for USB programming
Serial TX,D1,TX,GPIO 1,Used for USB programming
Servo 1,D9,D5,GPIO 14,Safe PWM pin
Servo 2,D6,D6,GPIO 12,Safe PWM pin
Servo 3,D5,D7,GPIO 13,Safe PWM pin
Button 1,A6,D3*,GPIO 0,Warning: Must be HIGH at boot
Button 2,A7,D4*,GPIO 2,Warning: Must be HIGH at boot
Button 3,A0,D0*,GPIO 16,Warning: No internal Pullup resistor
Button 4,D10,D8*,GPIO 15,Warning: Must be LOW at boot
Sensor (Sens),A1,ADS1115 A0,External,Connect to ADS1115 Module
Joystick X (AX),A2,ADS1115 A1,External,Connect to ADS1115 Module
Joystick Y (AY),A3,ADS1115 A2,External,Connect to ADS1115 Module

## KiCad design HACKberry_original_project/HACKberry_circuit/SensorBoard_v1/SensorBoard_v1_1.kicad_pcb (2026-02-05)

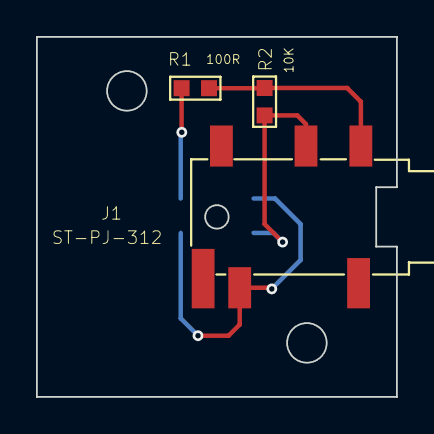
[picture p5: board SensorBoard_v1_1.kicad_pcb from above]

Board: 2 copper layers, 20.0 x 20.0 mm, 4 parts (1 on the bottom side), 4 nets.

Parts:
J1: ST-PJ-312; SUNTECH_ST-PJ-312
R1: 100R; R0603
R2: 10K; R0603
U1: QRE1113GR; 4LEADSMD

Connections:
GND: J1.L, U1.E, U1.K
unnamed: J1.R, R2.1, U1.C
unnamed: R1.1, U1.A
VCC: J1.COM1, R1.2, R2.2

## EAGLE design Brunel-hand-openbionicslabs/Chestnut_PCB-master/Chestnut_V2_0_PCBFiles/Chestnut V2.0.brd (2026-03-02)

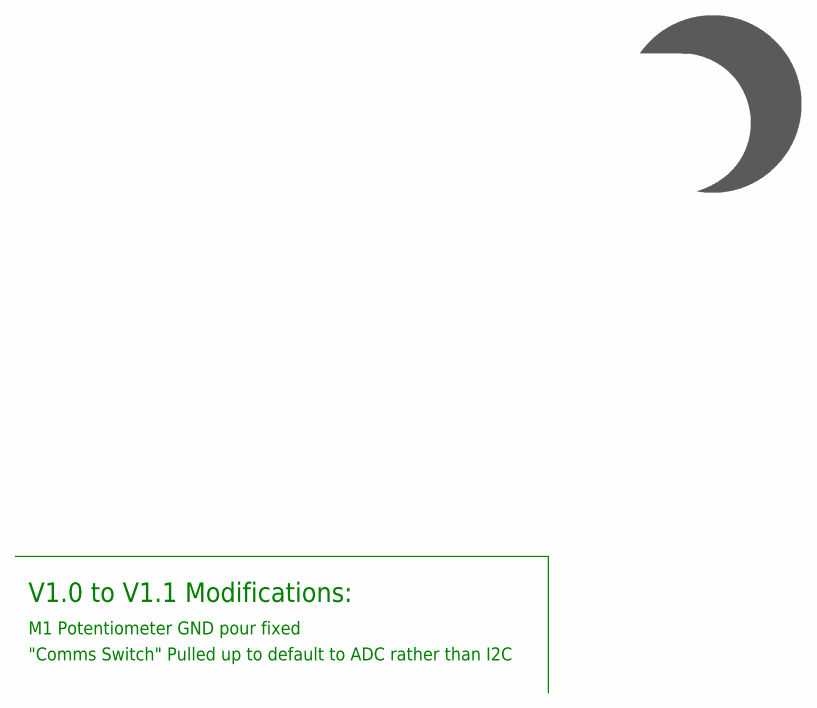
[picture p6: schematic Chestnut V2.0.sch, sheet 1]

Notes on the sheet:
V1.0 to V1.1 Modifications:
M1 Potentiometer GND pour fixed
"Comms Switch" Pulled up to default to ADC rather than I2C

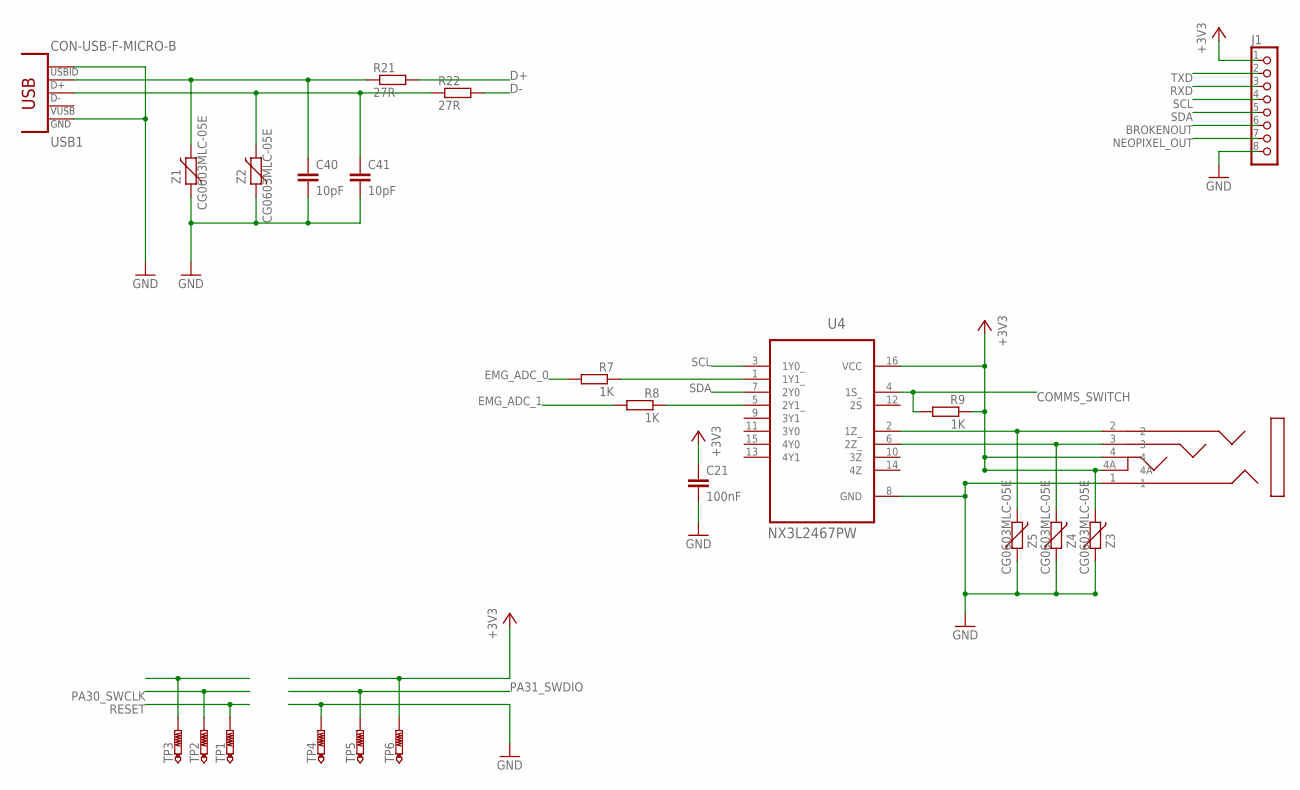
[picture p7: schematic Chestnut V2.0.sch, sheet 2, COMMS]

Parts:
C21: 100nF; C0402
C40, C41: 10pF; C0402
J1: CON_HEADER_1X08-PTH; M1X8
R7, R8, R9: 1K; R0402
R21, R22: 27R; R0402
TP1, TP2, TP3, TP4, TP5, TP6: PTR1TP11R; TP11R
U4: NX3L2467PW; SOP65P640X110-16N
U$7: LUMBERG_1503-13-VP3
USB1: CON-USB-F-MICRO-B; CONN_USB_MICRO-B
Z1, Z2, Z3, Z4, Z5: CG0603MLC-05E; CT/CN0603

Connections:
+3V3: C21.1, J1.1, R9.1, TP6.TP, U4.16 (VCC), U$7.4, U$7.4A, Z3.2; also elsewhere on the board
BROKENOUT: J1.6; also elsewhere on the board
COMMS_SWITCH: R9.2, U4.4 (1S_); also elsewhere on the board
D+: R21.2; also elsewhere on the board
D-: R22.2; also elsewhere on the board
EMG_ADC_0: R7.2; also elsewhere on the board
EMG_ADC_1: R8.2; also elsewhere on the board
GND: C21.2, C40.2, C41.2, J1.8, TP4.TP, U4.8 (GND), U$7.1, USB1.P4 (USBID), USB1.P5 (GND), Z1.1, Z2.1, Z3.1, Z4.1, Z5.1; also elsewhere on the board
unnamed: U4.6 (2Z_), U$7.3, Z4.2
unnamed: C41.1, R22.1, USB1.P2 (D-), Z2.2
unnamed: C40.1, R21.1, USB1.P3 (D+), Z1.2
unnamed: U4.2 (1Z_), U$7.2, Z5.2
unnamed: R7.1, U4.1 (1Y1_)
unnamed: R8.1, U4.5 (2Y1_)
NEOPIXEL_OUT: J1.7; also elsewhere on the board
PA30_SWCLK: TP2.TP; also elsewhere on the board
PA31_SWDIO: TP5.TP; also elsewhere on the board
RESET: TP1.TP; also elsewhere on the board
RXD: J1.3; also elsewhere on the board
SCL: J1.4, U4.3 (1Y0_); also elsewhere on the board
SDA: J1.5, U4.7 (2Y0); also elsewhere on the board
TXD: J1.2; also elsewhere on the board

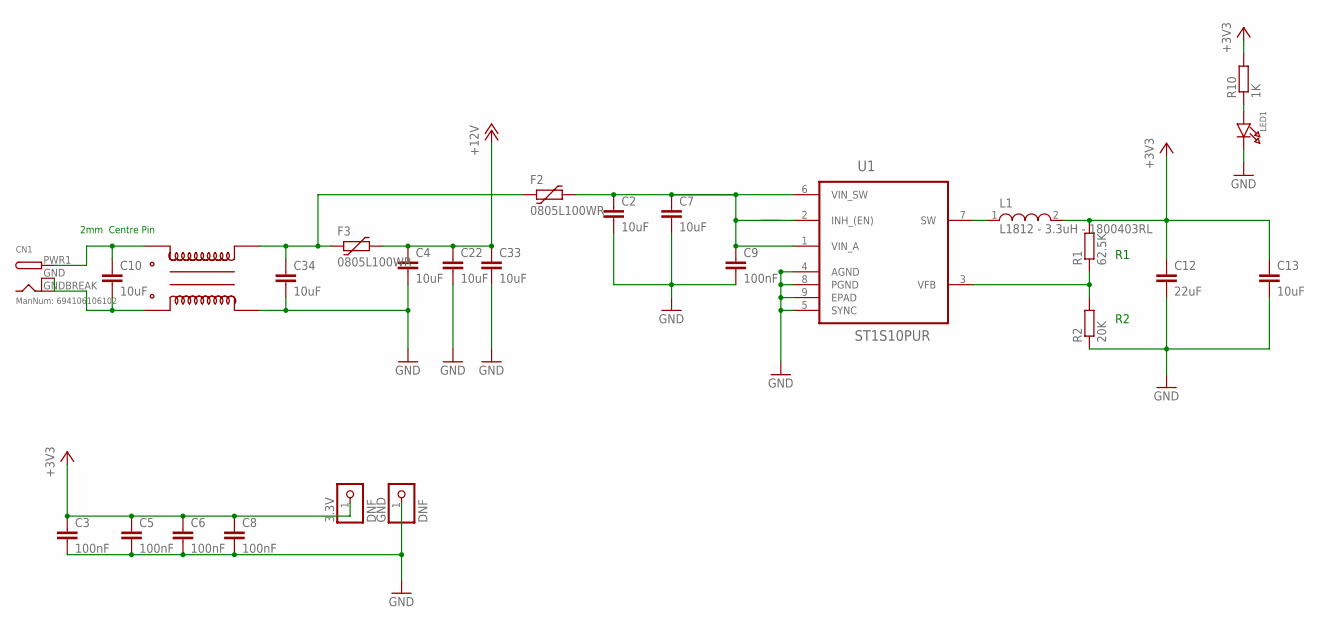
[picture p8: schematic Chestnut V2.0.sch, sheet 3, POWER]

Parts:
3.3V: DNF; 1X01_ROUND
C2, C4, C7, C10, C13, C22, C33, C34: 10uF; C0805
C3, C5, C6, C8, C9: 100nF; C0402
C12: 22uF; C1210
CN1: ManNum: 694106106102; DCJACK_2MM_SMT
F2, F3: 0805L100WR; PTC0805
GND: DNF; 1X01_ROUND
L1: L1812 - 3.3uH - 1800403RL; L1812
LED1: LED0603; CHIPLED_0603
R1: 62.5K; R0603
R2: 20K; R0603
R10: 1K; R0402
U1: ST1S10PUR; DFN400X400X100-9N
U$5: DLW5BTN501SQ2L

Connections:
12VFUSED: C2.1, C7.1, C9.1, F2.2, U1.1 (VIN_A), U1.2 (INH_(EN)), U1.6 (VIN_SW)
+3V3: 3.3V.1, C3.1, C5.1, C6.1, C8.1, C12.1, C13.1, L1.2, R1.2, R10.2; also elsewhere on the board
+12V: C4.1, C22.1, C33.1, F3.2; also elsewhere on the board
GND: C2.2, C3.2, C4.2, C5.2, C6.2, C7.2, C8.2, C9.2, C12.2, C13.2, C22.2, C33.2, C34.2, GND.1, LED1.C, R2.1, U1.4 (AGND), U1.5 (SYNC), U1.8 (PGND), U1.9 (EPAD), U$5.4; also elsewhere on the board
unnamed: LED1.A, R10.1
unnamed: L1.1, U1.7 (SW)
unnamed: C34.1, F2.1, F3.1, U$5.2
unnamed: R1.1, R2.2, U1.3 (VFB)
unnamed: C10.2, CN1.GND (GNDBREAK), CN1.GNDBREAK (GND), U$5.3
unnamed: C10.1, CN1.PWR1 (PWR), U$5.1

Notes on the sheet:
2mm Centre Pin

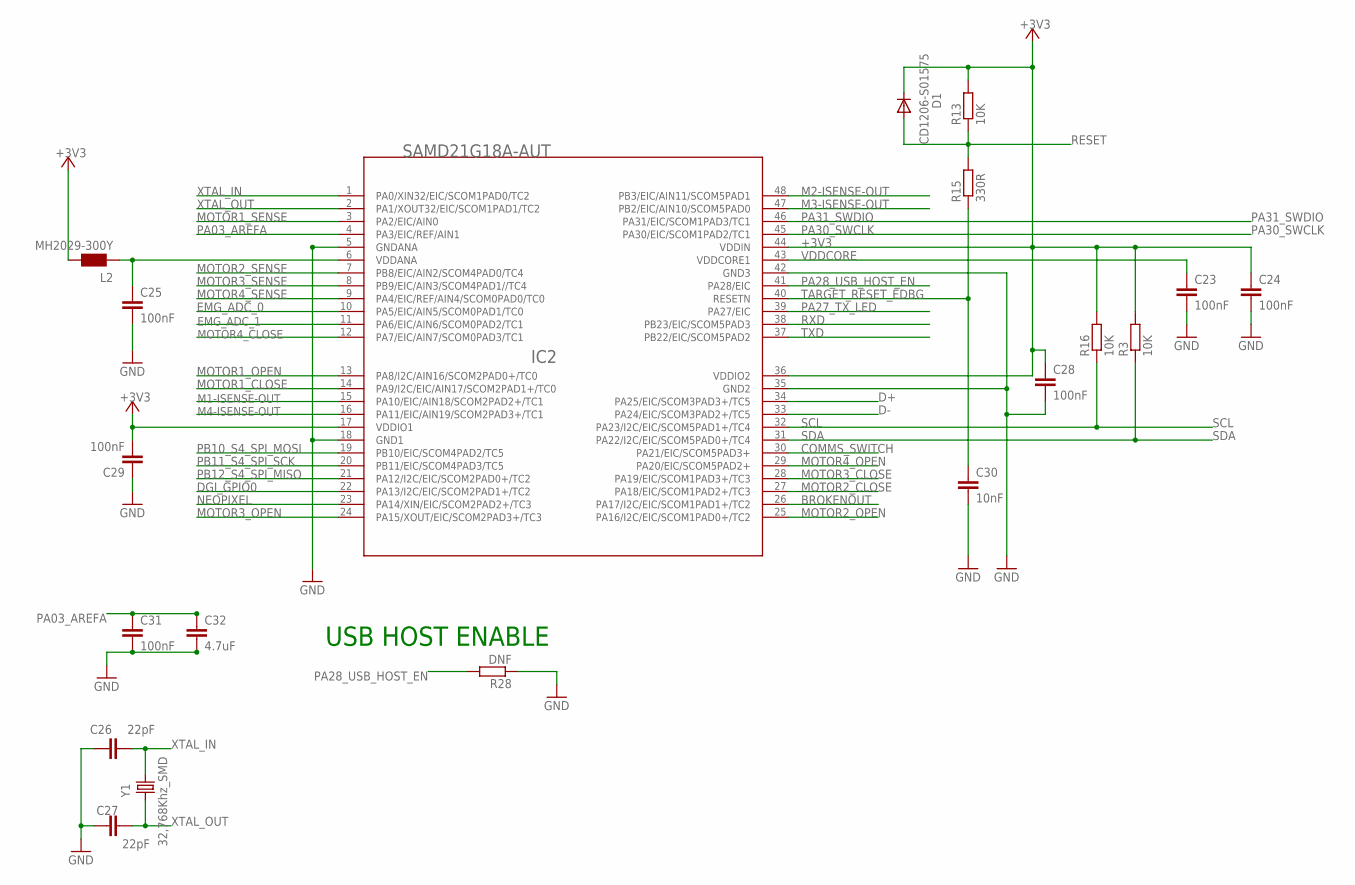
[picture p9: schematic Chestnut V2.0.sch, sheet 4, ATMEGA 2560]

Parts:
C23, C24, C25, C28, C29, C31: 100nF; C0402
C26, C27: 22pF; C0402
C30: 10nF; C0402
C32: 4.7uF; C0603
D1: CD1206-S01575; MINIMELF
IC2: SAMD21G18A-AUT; INTEGRATEDCIRCUITS_TQFP48-7X7
L2: MH2029-300Y; 0805
R3, R13, R16: 10K; R0402
R15: 330R; R0402
R28: DNF; R0402
Y1: 32,768Khz_SMD; RESONATOR_EPSON_FC_145

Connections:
+3V3: C24.1, C28.1, C29.2, D1.C, IC2.17 (VDDIO1), IC2.36 (VDDIO2), IC2.44 (VDDIN), L2.2, R3.2, R13.2, R16.2; also elsewhere on the board
BROKENOUT: IC2.26 (PA17/I2C/EIC/SCOM1PAD1+/TC2); also elsewhere on the board
COMMS_SWITCH: IC2.30 (PA21/EIC/SCOM5PAD3+); also elsewhere on the board
D+: IC2.34 (PA25/EIC/SCOM3PAD3+/TC5); also elsewhere on the board
D-: IC2.33 (PA24/EIC/SCOM3PAD2+/TC5); also elsewhere on the board
DGI_GPIO0: IC2.22 (PA13/I2C/EIC/SCOM2PAD1+/TC2)
EMG_ADC_0: IC2.10 (PA5/EIC/AIN5/SCOM0PAD1/TC0); also elsewhere on the board
EMG_ADC_1: IC2.11 (PA6/EIC/AIN6/SCOM0PAD2/TC1); also elsewhere on the board
GND: C23.2, C24.2, C25.2, C26.1, C27.1, C28.2, C29.1, C30.2, C31.2, C32.2, IC2.5 (GNDANA), IC2.18 (GND1), IC2.35 (GND2), IC2.42 (GND3), R28.1; also elsewhere on the board
M1-ISENSE-OUT: IC2.15 (PA10/EIC/AIN18/SCOM2PAD2+/TC1); also elsewhere on the board
M2-ISENSE-OUT: IC2.48 (PB3/EIC/AIN11/SCOM5PAD1); also elsewhere on the board
M3-ISENSE-OUT: IC2.47 (PB2/EIC/AIN10/SCOM5PAD0); also elsewhere on the board
M4-ISENSE-OUT: IC2.16 (PA11/EIC/AIN19/SCOM2PAD3+/TC1); also elsewhere on the board
MOTOR1_CLOSE: IC2.14 (PA9/I2C/EIC/AIN17/SCOM2PAD1+/TC0); also elsewhere on the board
MOTOR1_OPEN: IC2.13 (PA8/I2C/AIN16/SCOM2PAD0+/TC0); also elsewhere on the board
MOTOR1_SENSE: IC2.3 (PA2/EIC/AIN0); also elsewhere on the board
MOTOR2_CLOSE: IC2.27 (PA18/EIC/SCOM1PAD2+/TC3); also elsewhere on the board
MOTOR2_OPEN: IC2.25 (PA16/I2C/EIC/SCOM1PAD0+/TC2); also elsewhere on the board
MOTOR2_SENSE: IC2.7 (PB8/EIC/AIN2/SCOM4PAD0/TC4); also elsewhere on the board
MOTOR3_CLOSE: IC2.28 (PA19/EIC/SCOM1PAD3+/TC3); also elsewhere on the board
MOTOR3_OPEN: IC2.24 (PA15/XOUT/EIC/SCOM2PAD3+/TC3); also elsewhere on the board
MOTOR3_SENSE: IC2.8 (PB9/EIC/AIN3/SCOM4PAD1//TC4); also elsewhere on the board
MOTOR4_CLOSE: IC2.12 (PA7/EIC/AIN7/SCOM0PAD3/TC1); also elsewhere on the board
MOTOR4_OPEN: IC2.29 (PA20/EIC/SCOM5PAD2+); also elsewhere on the board
MOTOR4_SENSE: IC2.9 (PA4/EIC/REF/AIN4/SCOM0PAD0/TC0); also elsewhere on the board
unnamed: C25.1, IC2.6 (VDDANA), L2.1
NEOPIXEL: IC2.23 (PA14/XIN/EIC/SCOM2PAD2+/TC3); also elsewhere on the board
PA03_AREFA: C31.1, C32.1, IC2.4 (PA3/EIC/REF/AIN1)
PA27_TX_LED: IC2.39 (PA27/EIC)
PA28_USB_HOST_EN: IC2.41 (PA28/EIC), R28.2
PA30_SWCLK: IC2.45 (PA30/EIC/SCOM1PAD2/TC1); also elsewhere on the board
PA31_SWDIO: IC2.46 (PA31/EIC/SCOM1PAD3/TC1); also elsewhere on the board
PB10_S4_SPI_MOSI: IC2.19 (PB10/EIC/SCOM4PAD2/TC5)
PB11_S4_SPI_SCK: IC2.20 (PB11/EIC/SCOM4PAD3/TC5)
PB12_S4_SPI_MISO: IC2.21 (PA12/I2C/EIC/SCOM2PAD0+/TC2)
RESET: D1.A, R13.1, R15.2; also elsewhere on the board
RXD: IC2.38 (PB23/EIC/SCOM5PAD3); also elsewhere on the board
SCL: IC2.32 (PA23/I2C/EIC/SCOM5PAD1+/TC4), R16.1; also elsewhere on the board
SDA: IC2.31 (PA22/I2C/EIC/SCOM5PAD0+/TC4), R3.1; also elsewhere on the board
TARGET_RESET_EDBG: C30.1, IC2.40 (RESETN), R15.1
TXD: IC2.37 (PB22/EIC/SCOM5PAD2); also elsewhere on the board
VDDCORE: C23.1, IC2.43 (VDDCORE1)
XTAL_IN: C26.2, IC2.1 (PA0/XIN32/EIC/SCOM1PAD0/TC2), Y1.P$2 (2)
XTAL_OUT: C27.2, IC2.2 (PA1/XOUT32/EIC/SCOM1PAD1/TC2), Y1.P$1 (1)

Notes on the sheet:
USB HOST ENABLE

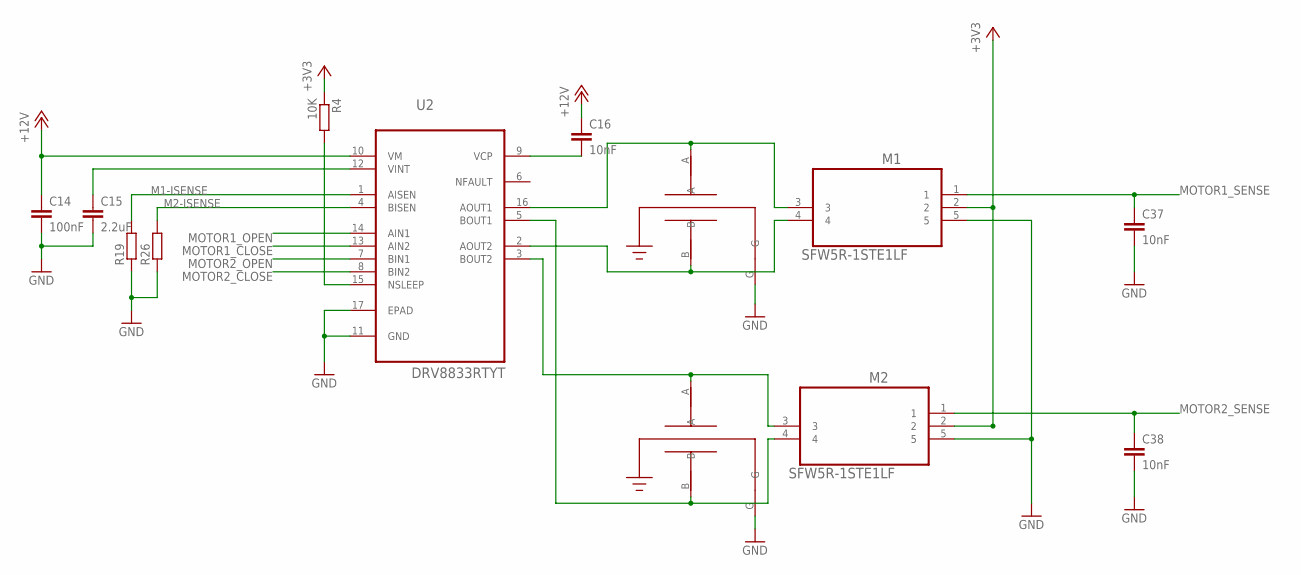
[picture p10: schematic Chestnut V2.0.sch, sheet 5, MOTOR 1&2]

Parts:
C14: 100nF; C0402
C15: 2.2uF; C0603
C16, C37, C38: 10nF; C0402
M1, M2: SFW5R-1STE1LF; FCI_SFW5R-1STE1LF
R4: 10K; R0402
R19, R26: R-EU_R0805; R0805
U2: DRV8833RTYT; QFN65P400X400X80-17N
U$8, U$19: 101X14N330MV4T_X2Y_0603

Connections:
+3V3: M1.2, M2.2, R4.1; also elsewhere on the board
+12V: C14.1, C16.1, U2.10 (VM); also elsewhere on the board
GND: C14.2, C15.2, C37.2, C38.2, M1.5, M2.5, R19.1, R26.1, U2.11 (GND), U2.17 (EPAD), U$8.G, U$19.G; also elsewhere on the board
M1-ISENSE: R19.2, U2.1 (AISEN); also elsewhere on the board
M2-ISENSE: R26.2, U2.4 (BISEN); also elsewhere on the board
MOTOR1_CLOSE: U2.13 (AIN2); also elsewhere on the board
MOTOR1_OPEN: U2.14 (AIN1); also elsewhere on the board
MOTOR1_SENSE: C37.1, M1.1; also elsewhere on the board
MOTOR2_CLOSE: U2.8 (BIN2); also elsewhere on the board
MOTOR2_OPEN: U2.7 (BIN1); also elsewhere on the board
MOTOR2_SENSE: C38.1, M2.1; also elsewhere on the board
unnamed: C16.2, U2.9 (VCP)
unnamed: M1.3, U2.16 (AOUT1), U$19.A
unnamed: M1.4, U2.2 (AOUT2), U$19.B
unnamed: M2.4, U2.5 (BOUT1), U$8.B
unnamed: M2.3, U2.3 (BOUT2), U$8.A
unnamed: R4.2, U2.15 (NSLEEP)
unnamed: C15.1, U2.12 (VINT)

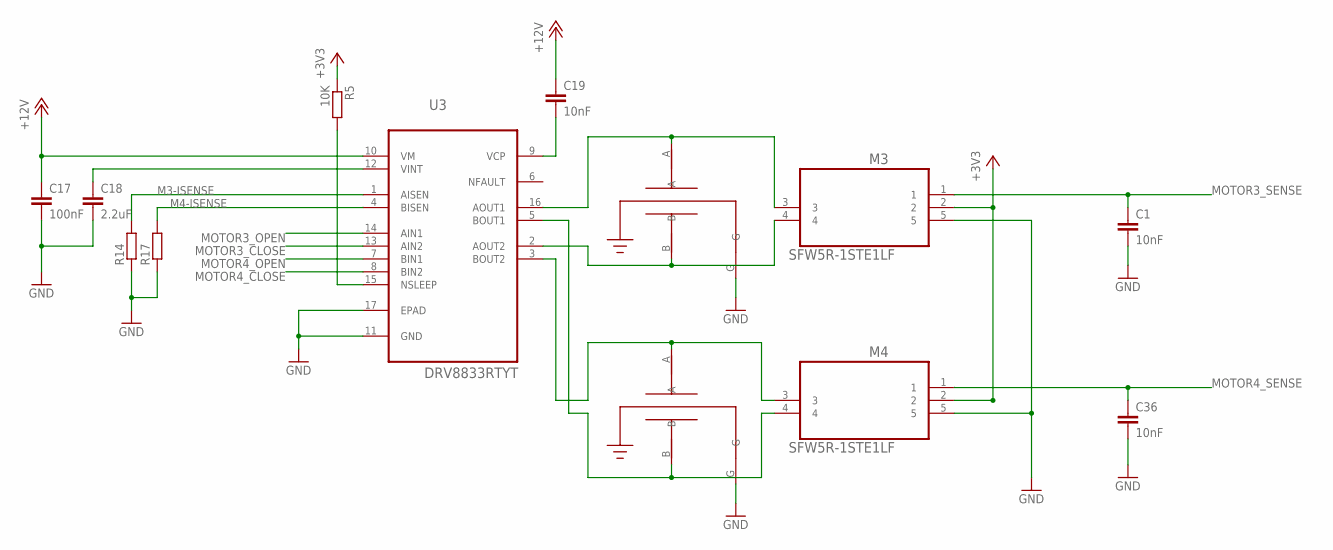
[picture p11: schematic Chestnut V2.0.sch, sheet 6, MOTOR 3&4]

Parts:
C1, C19, C36: 10nF; C0402
C17: 100nF; C0402
C18: 2.2uF; C0603
M3, M4: SFW5R-1STE1LF; FCI_SFW5R-1STE1LF
R5: 10K; R0402
R14, R17: R-EU_R0805; R0805
U3: DRV8833RTYT; QFN65P400X400X80-17N
U$9, U$10: 101X14N330MV4T_X2Y_0603

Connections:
+3V3: M3.2, M4.2, R5.1; also elsewhere on the board
+12V: C17.1, C19.1, U3.10 (VM); also elsewhere on the board
GND: C1.2, C17.2, C18.2, C36.2, M3.5, M4.5, R14.1, R17.1, U3.11 (GND), U3.17 (EPAD), U$9.G, U$10.G; also elsewhere on the board
M3-ISENSE: R14.2, U3.1 (AISEN); also elsewhere on the board
M4-ISENSE: R17.2, U3.4 (BISEN); also elsewhere on the board
MOTOR3_CLOSE: U3.13 (AIN2); also elsewhere on the board
MOTOR3_OPEN: U3.14 (AIN1); also elsewhere on the board
MOTOR3_SENSE: C1.1, M3.1; also elsewhere on the board
MOTOR4_CLOSE: U3.8 (BIN2); also elsewhere on the board
MOTOR4_OPEN: U3.7 (BIN1); also elsewhere on the board
MOTOR4_SENSE: C36.1, M4.1; also elsewhere on the board
unnamed: M3.3, U3.16 (AOUT1), U$9.A
unnamed: M3.4, U3.2 (AOUT2), U$9.B
unnamed: M4.4, U3.5 (BOUT1), U$10.B
unnamed: M4.3, U3.3 (BOUT2), U$10.A
unnamed: C19.2, U3.9 (VCP)
unnamed: C18.1, U3.12 (VINT)
unnamed: R5.2, U3.15 (NSLEEP)

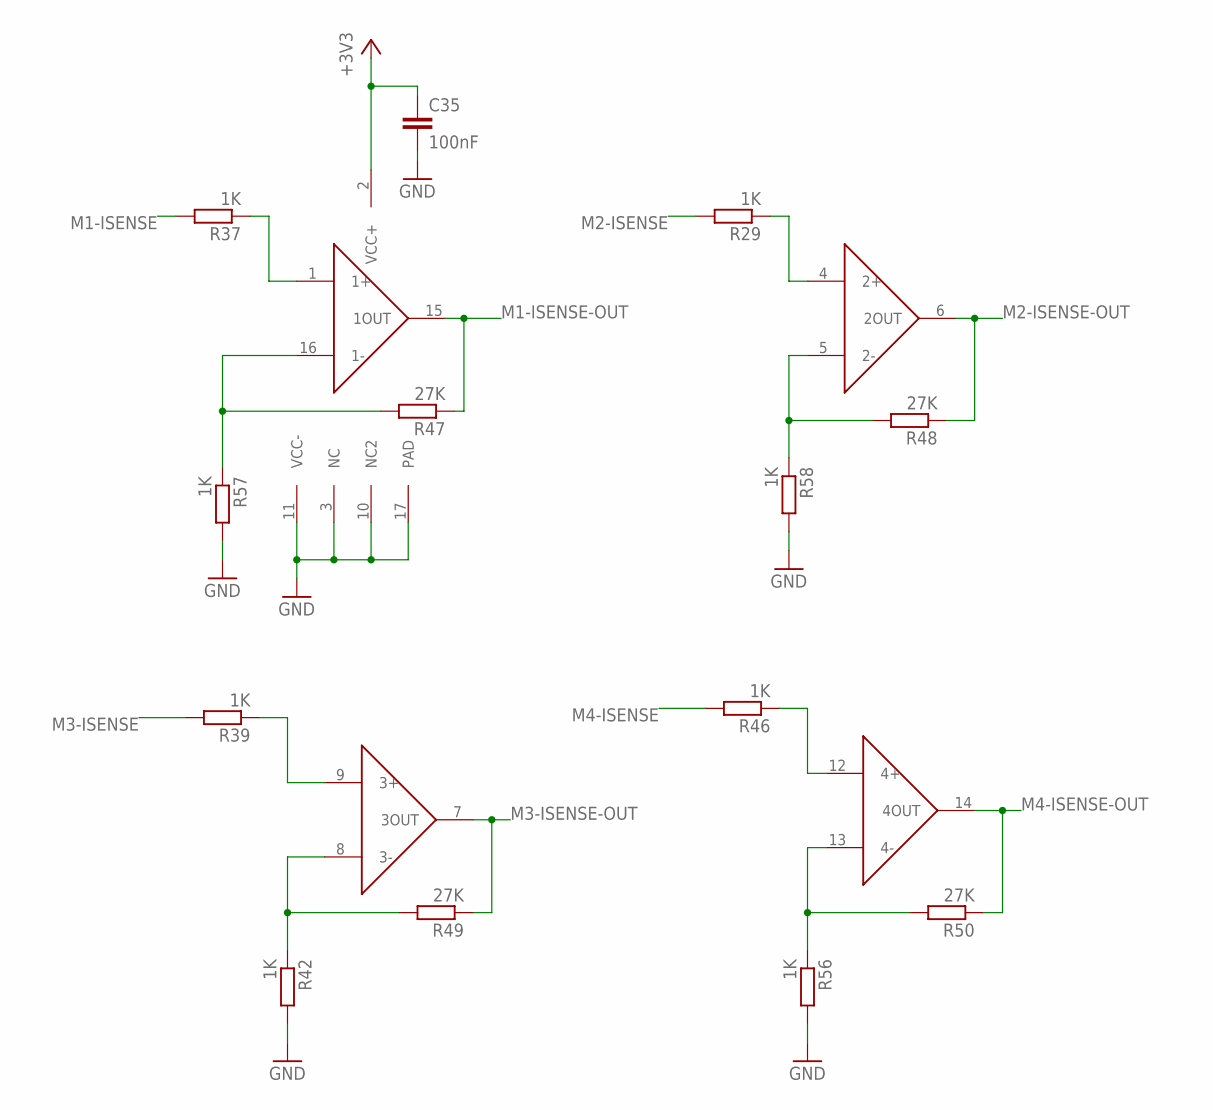
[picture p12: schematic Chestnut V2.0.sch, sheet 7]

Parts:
C35: 100nF; C0402
R29, R37, R39, R42, R46, R56, R57, R58: 1K; R0402
R47, R48, R49, R50: 27K; R0402
U$15: TSZ124IQ4T

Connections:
+3V3: C35.1, U$15.2 (VCC+); also elsewhere on the board
GND: C35.2, R42.2, R56.2, R57.2, R58.2, U$15.3 (NC), U$15.10 (NC2), U$15.11 (VCC-), U$15.17 (PAD); also elsewhere on the board
M1-ISENSE: R37.2; also elsewhere on the board
M1-ISENSE-OUT: R47.1, U$15.15 (1OUT); also elsewhere on the board
M2-ISENSE: R29.2; also elsewhere on the board
M2-ISENSE-OUT: R48.1, U$15.6 (2OUT); also elsewhere on the board
M3-ISENSE: R39.2; also elsewhere on the board
M3-ISENSE-OUT: R49.1, U$15.7 (3OUT); also elsewhere on the board
M4-ISENSE: R46.2; also elsewhere on the board
M4-ISENSE-OUT: R50.1, U$15.14 (4OUT); also elsewhere on the board
unnamed: R37.1, U$15.1 (1+)
unnamed: R29.1, U$15.4 (2+)
unnamed: R39.1, U$15.9 (3+)
unnamed: R47.2, R57.1, U$15.16 (1-)
unnamed: R46.1, U$15.12 (4+)
unnamed: R48.2, R58.1, U$15.5 (2-)
unnamed: R42.1, R49.2, U$15.8 (3-)
unnamed: R50.2, R56.1, U$15.13 (4-)

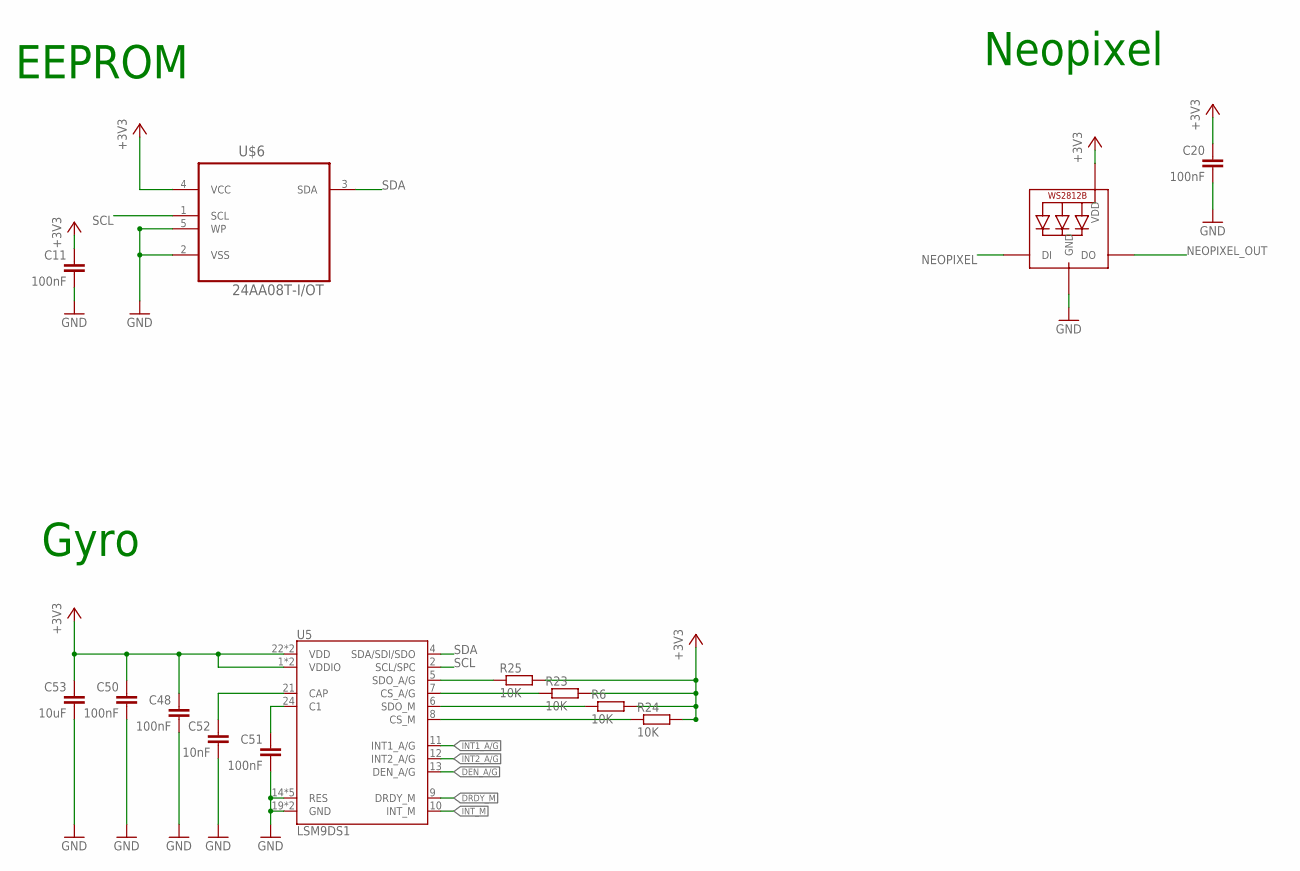
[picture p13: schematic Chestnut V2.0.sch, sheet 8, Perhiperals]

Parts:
C11, C20, C48, C50, C51: 100nF; C0402
C52: 10nF; C0402
C53: 10uF; C0805
LED2: WS2812B3535; LED3535
R6, R23, R24, R25: 10K; R0402
U5: LSM9DS1; LGA24-8X4
U$6: 24AA08T-I/OT; SOT95P290X145-5N

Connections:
+3V3: C11.1, C20.1, C48.1, C50.1, C53.1, LED2.2 (VDD), R6.2, R23.2, R24.2, R25.2, U5.1 (VDDIO), U5.3 (VDDIO), U5.22 (VDD), U5.23 (VDD), U$6.4 (VCC); also elsewhere on the board
C1: C51.1, U5.24 (C1)
CAP: C52.1, U5.21 (CAP)
DEN_A/G: U5.13 (DEN_A/G)
DRDY_M: U5.9 (DRDY_M)
GND: C11.2, C20.2, C48.2, C50.2, C51.2, C52.2, C53.2, LED2.4 (GND), U5.14 (RES), U5.15 (RES), U5.16 (RES), U5.17 (RES), U5.18 (RES), U5.19 (GND), U5.20 (GND), U$6.2 (VSS), U$6.5 (WP); also elsewhere on the board
INT1_A/G: U5.11 (INT1_A/G)
INT2_A/G: U5.12 (INT2_A/G)
INT_M: U5.10 (INT_M)
unnamed: R25.1, U5.5 (SDO_A/G)
unnamed: R23.1, U5.7 (CS_A/G)
unnamed: R6.1, U5.6 (SDO_M)
unnamed: R24.1, U5.8 (CS_M)
NEOPIXEL: LED2.1 (DI); also elsewhere on the board
NEOPIXEL_OUT: LED2.3 (DO); also elsewhere on the board
SCL: U5.2 (SCL/SPC), U$6.1 (SCL); also elsewhere on the board
SDA: U5.4 (SDA/SDI/SDO), U$6.3 (SDA); also elsewhere on the board

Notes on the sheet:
EEPROM
Gyro
Neopixel

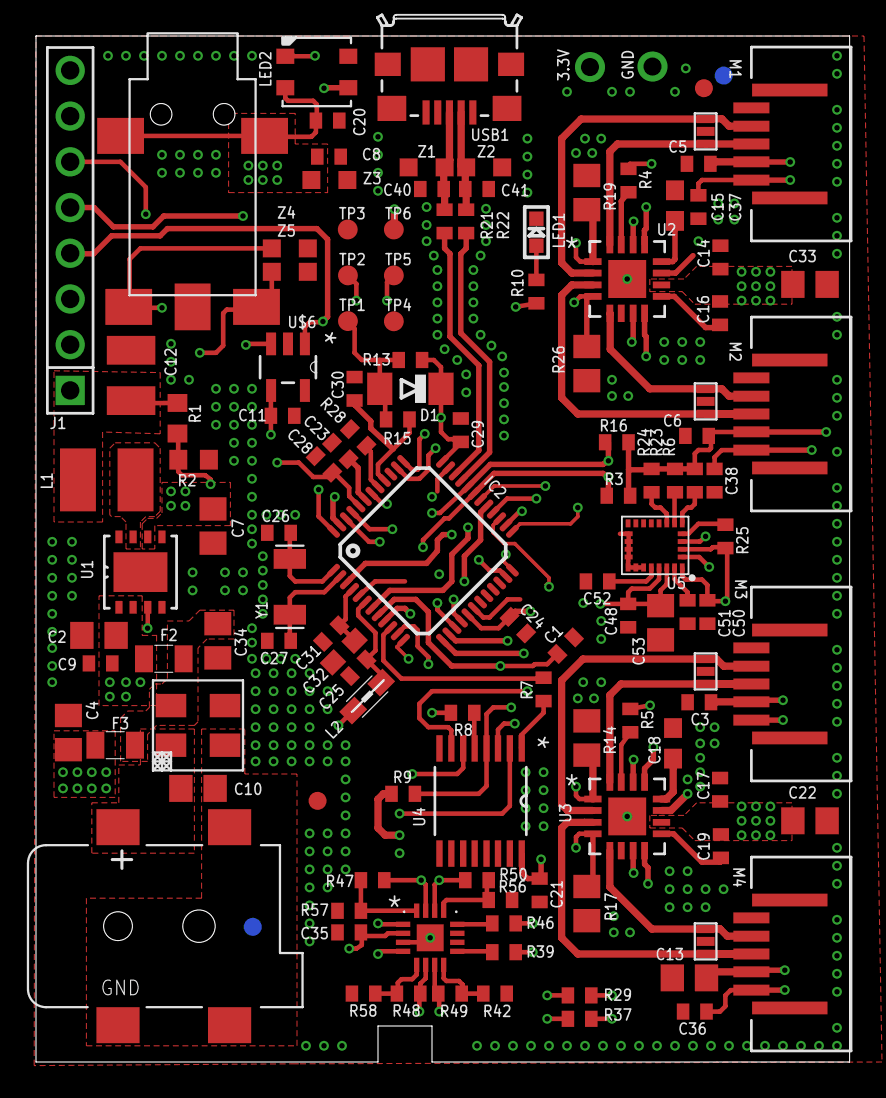
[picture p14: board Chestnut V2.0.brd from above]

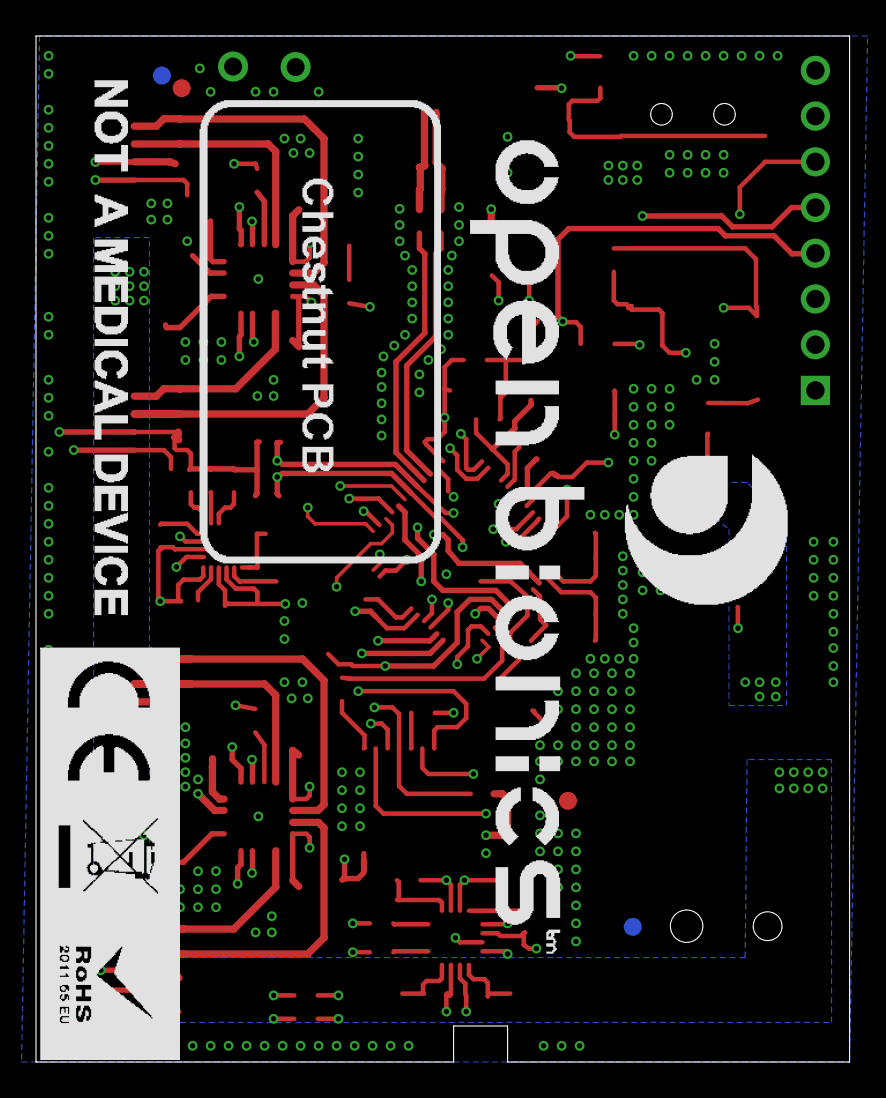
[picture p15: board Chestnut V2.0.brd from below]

Board: 4 copper layers, 45.2 x 57.0 mm, 126 parts (2 on the bottom side), 86 nets.

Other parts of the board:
U$1, U$2, U$3, U$4: FIDUCIAL_G10

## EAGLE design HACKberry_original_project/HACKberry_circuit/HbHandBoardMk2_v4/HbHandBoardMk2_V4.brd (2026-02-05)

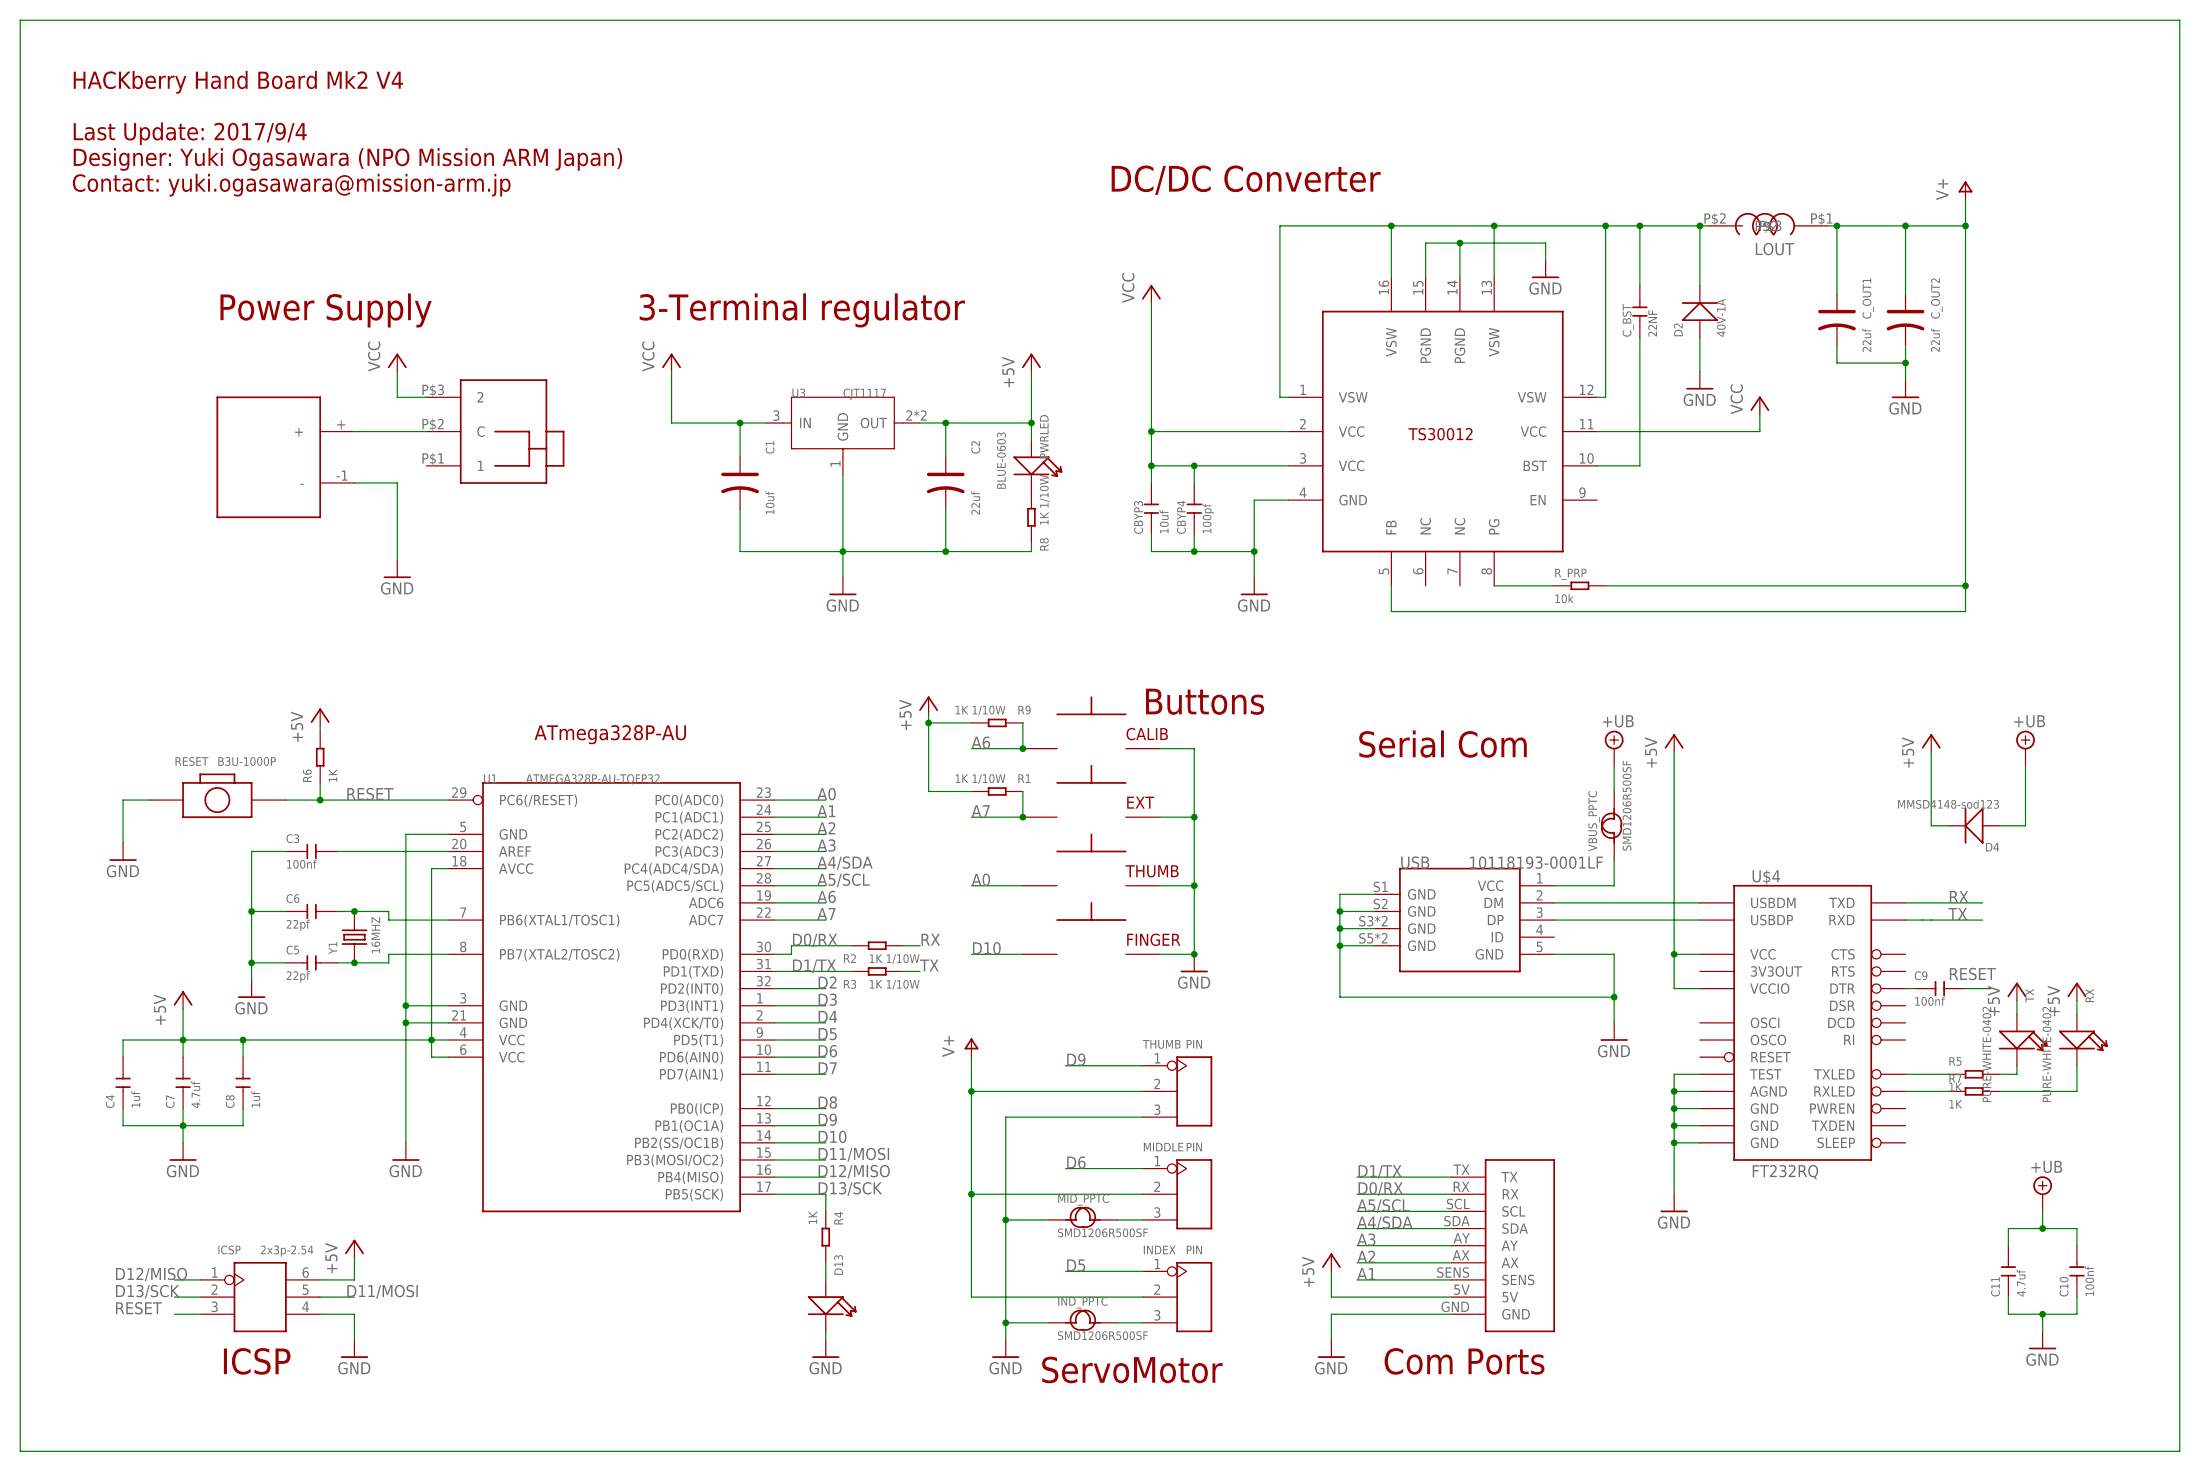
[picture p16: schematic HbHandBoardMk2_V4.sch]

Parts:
C1: 10uf; AVX-A
C2: 22uf; AVX-A
C3, C9, C10: 100nf; C0402
C4, C8: 1uf; C0402
C5, C6: 22pf; C0402
C7, C11: 4.7uf; C0603
CALIB: SKRGAQD010
CBYP3: 10uf; C0805
CBYP4: 100pf; C0402
C_BST: 22NF; C0402
C_OUT1, C_OUT2: 22uf; AVX-B
D2: 40V-1A; DO-214AC
D4: MMSD4148-sod123; SOD-123
D13: SMD-LED-CLEAR-GREEN(0805); LED-0805
EXT: SKRGAQD010
FINGER: SKRGAQD010
ICSP: 2x3p-2.54; H2X3-2.54
INDEX: PIN; H3-2.54
IND_PPTC: SMD1206R500SF; F1206
LOUT: SPM3015T-4R7M-LR
MIDDLE: PIN; H3-2.54
MID_PPTC: SMD1206R500SF; F1206
PWRLED: BLUE-0603; LED-0603
PWR_SW: SS12SDP2
R1, R2, R3, R8, R9: 1K 1/10W; R0603
R4: 1K; R0805
R5, R6, R7: 1K; R0402
RESET: B3U-1000P; SW2-SMD-3.0X2.5X1.2+0.4MM
RX: PURE-WHITE-0402; LED-0402
R_PRP: 10k; R0402
THUMB: PIN; H3-2.54
THUMB_BUTTON: SKRGAQD010
TX: PURE-WHITE-0402; LED-0402
U1: ATMEGA328P-AU-TQFP32; TQFP32-0.8-7X7MM
U3: CJT1117; SOT-223
U$1: 9PADS
U$3: DCJACK; DCJ3P-14.2X11.0X9.0MM
U$4: FT232RQ; QFN-32
U$6: TS30012; VQFN16
USB: 10118193-0001LF; MICRO-USB5+6P-SMD-0.65-B
VBUS_PPTC: SMD1206R500SF; F1206
Y1: 16MHZ; X2-SMD-5.0X3.2X1.3MM

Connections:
+5V: C2.+, C4.2, C7.2, C8.2, D4.-, ICSP.6, PWRLED.+, R1.2, R6.2, R9.2, RX.+, TX.+, U1.4 (VCC), U1.6 (VCC), U1.18 (AVCC), U3.2 (OUT), U3.TER (OUT), U$1.5V, U$4.1 (VCCIO), U$4.19 (VCC)
+UB: C10.2, C11.2, D4.+, VBUS_PPTC.2
A0: THUMB_BUTTON.P$1 (1), U1.23 (PC0(ADC0))
A1: U1.24 (PC1(ADC1)), U$1.SENS
A2: U1.25 (PC2(ADC2)), U$1.AX
A3: U1.26 (PC3(ADC3)), U$1.AY
A4/SDA: U1.27 (PC4(ADC4/SDA)), U$1.SDA
A5/SCL: U1.28 (PC5(ADC5/SCL)), U$1.SCL
A6: CALIB.P$1 (1), R9.1, U1.19 (ADC6)
A7: EXT.P$1 (1), R1.1, U1.22 (ADC7)
D0/RX: R2.1, U1.30 (PD0(RXD)), U$1.RX
D1/TX: R3.1, U1.31 (PD1(TXD)), U$1.TX
D2: U1.32 (PD2(INT0))
D3: U1.1 (PD3(INT1))
D4: U1.2 (PD4(XCK/T0))
D5: INDEX.1, U1.9 (PD5(T1))
D6: MIDDLE.1, U1.10 (PD6(AIN0))
D7: U1.11 (PD7(AIN1))
D8: U1.12 (PB0(ICP))
D9: THUMB.1, U1.13 (PB1(OC1A))
D10: FINGER.P$1 (1), U1.14 (PB2(SS/OC1B))
D11/MOSI: ICSP.5, U1.15 (PB3(MOSI/OC2))
D12/MISO: ICSP.1, U1.16 (PB4(MISO))
D13/SCK: ICSP.2, R4.1, U1.17 (PB5(SCK))
GND: C1.-, C2.-, C3.1, C4.1, C5.1, C6.1, C7.1, C8.1, C10.1, C11.1, CALIB.P$2 (2), CBYP3.1, CBYP4.1, C_OUT1.-, C_OUT2.-, D2.1 (+), D13.-, EXT.P$2 (2), FINGER.P$2 (2), ICSP.4, IND_PPTC.1, MID_PPTC.1, R8.1, RESET.1, THUMB.3, THUMB_BUTTON.P$2 (2), U1.3 (GND), U1.5 (GND), U1.21 (GND), U3.1 (GND), U$1.GND, U$3.-1 (-), U$4.4 (GND), U$4.17 (GND), U$4.20 (GND), U$4.24 (AGND), U$4.26 (TEST), U$6.4 (GND), U$6.14 (PGND), U$6.15 (PGND), USB.5 (GND), USB.S1 (GND), USB.S2 (GND), USB.S3 (GND), USB.S4 (GND), USB.S5 (GND), USB.S6 (GND)
unnamed: PWRLED.-, R8.2
unnamed: C5.2, U1.8 (PB7(XTAL2/TOSC2)), Y1.1
unnamed: C6.2, U1.7 (PB6(XTAL1/TOSC1)), Y1.2
unnamed: D13.+, R4.2
unnamed: U$4.15 (USBDM), USB.2 (DM)
unnamed: C3.2, U1.20 (AREF)
unnamed: U$4.14 (USBDP), USB.3 (DP)
unnamed: C_BST.2, D2.2 (-), LOUT.P$2, U$6.1 (VSW), U$6.12 (VSW), U$6.13 (VSW), U$6.16 (VSW)
unnamed: PWR_SW.P$2 (C), U$3.+
unnamed: C_BST.1, U$6.10 (BST)
unnamed: INDEX.3, IND_PPTC.2
unnamed: MIDDLE.3, MID_PPTC.2
unnamed: R_PRP.1, U$6.8 (PG)
unnamed: C9.1, U$4.31 (DTR)
unnamed: USB.1 (VCC), VBUS_PPTC.1
unnamed: R5.1, U$4.22 (TXLED)
unnamed: R7.1, U$4.21 (RXLED)
unnamed: R5.2, TX.-
unnamed: R7.2, RX.-
RESET: C9.2, ICSP.3, R6.1, RESET.2, U1.29 (PC6(/RESET))
RX: R2.2, U$4.30 (TXD)
TX: R3.2, U$4.2 (RXD)
V+: C_OUT1.+, C_OUT2.+, INDEX.2, LOUT.P$1, MIDDLE.2, R_PRP.2, THUMB.2, U$6.5 (FB)
VCC: C1.+, CBYP3.2, CBYP4.2, PWR_SW.P$3 (2), U3.3 (IN), U$6.2 (VCC), U$6.3 (VCC), U$6.11 (VCC)

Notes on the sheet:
ATmega328P-AU
Power Supply
ServoMotor
3-Terminal regulator
Buttons
Com Ports
DC/DC Converter
HACKberry Hand Board Mk2 V4 Last Update: 2017/9/4 Designer: Yuki Ogasawara (NPO Mission ARM Japan) Contact: yuki.ogasawara@mission-arm.jp
ICSP
Serial Com
FINGER
THUMB
CALIB
EXT

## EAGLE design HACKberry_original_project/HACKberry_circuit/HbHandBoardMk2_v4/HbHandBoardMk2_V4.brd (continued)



Board: 2 copper layers, 58.5 x 43.5 mm, 54 parts (4 on the bottom side), 44 nets.

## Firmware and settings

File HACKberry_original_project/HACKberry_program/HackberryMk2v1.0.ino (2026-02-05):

/*
 *  Arduino micro code for HACKberry Mk2.
 *  Origially created by exiii Inc.
 *  edited by Kouki Shinjo on 2018/04/26
 */
#include <Servo.h>

//Settings
const boolean isRight = 0;//right:1, left:0
const int outThumbMax = 95;//right:open, left:close
const int outIndexMax = 100;//right:open, left:close
const int outOtherMax = 75;//right:open, left:close
const int outThumbMin = 10;//right:close, left:open
const int outIndexMin = 0;//right:close, left:open
const int outOtherMin = 20;//right:close, left:open
const int speedMax = 6;
const int speedMin = 0;
const int speedReverse = -3;
const int thSpeedReverse = 15;//0-100
const int thSpeedZero = 30;//0-100
const boolean onSerial = 0; // 1 is not recommended

//Pin
int pinButtonCalib; //start calibration
int pinButtonTBD; // No function implemented yet.
int pinButtonThumb; // open/close thumb
int pinButtonOther; //lock/unlock other three fingers
int pinServoIndex;
int pinServoOther;
int pinServoThumb;
int pinSensor; //sensor input

//Hardware
Servo servoIndex; //index finger
Servo servoOther; //other three fingers
Servo servoThumb; //thumb

//Software
boolean isThumbOpen = 1;
boolean isOtherLock = 0;
int swCount0,swCount1,swCount2,swCount3 = 0;
int sensorValue = 0; // value read from the sensor
int sensorMax = 700;
int sensorMin = 0;
int speed = 0;
int position = 0;
const int positionMax = 100;
const int positionMin = 0;
int prePosition = 0;
int outThumb,outIndex,outOther = 90;
int outThumbOpen,outThumbClose,outIndexOpen,outIndexClose,outOtherOpen,outOtherClose;

void setup() {
    if (onSerial)  Serial.begin(9600);

    // Pin Configuration
    pinButtonCalib = A6;
    pinButtonTBD   = A7;
    pinButtonThumb = A0;
    pinButtonOther = 10;
    pinServoIndex  = 5;
    pinServoOther  = 6;
    pinServoThumb  = 9;
    pinSensor      = A1;

    if(isRight){
        outThumbOpen=outThumbMax; outThumbClose=outThumbMin;
        outIndexOpen=outIndexMax; outIndexClose=outIndexMin;
        outOtherOpen=outOtherMax; outOtherClose=outOtherMin;
    } else {
        outThumbOpen=outThumbMin; outThumbClose=outThumbMax;
        outIndexOpen=outIndexMin; outIndexClose=outIndexMax;
        outOtherOpen=outOtherMin; outOtherClose=outOtherMax;
    }
    servoIndex.attach(pinServoIndex);//index
    servoOther.attach(pinServoOther);//other
    servoThumb.attach(pinServoThumb);//thumb

    pinMode(pinButtonCalib, INPUT_PULLUP);
    pinMode(pinButtonTBD,   INPUT_PULLUP);
    pinMode(pinButtonThumb, INPUT_PULLUP);
    pinMode(pinButtonOther, INPUT_PULLUP);
}

void loop() {
    //==waiting for calibration==
    if(onSerial) Serial.println("======Waiting for Calibration======");
    while (1) {
        servoIndex.write(outIndexOpen);
        servoOther.write(outOtherOpen);
        servoThumb.write(outThumbOpen);
        if(onSerial) serialMonitor();
        delay(10);
        if (readButton(pinButtonCalib) == LOW) {
            calibration();
            break;
        }
    }
    //==control==
    position = positionMin;
    prePosition = positionMin;
    while (1) {
        if (readButton(pinButtonCalib) == LOW) swCount0 += 1;
        else swCount0 = 0;
        if (swCount0 == 10) {
            swCount0 = 0;
            calibration();
        }
        if (readButton(pinButtonTBD) == LOW) swCount1 += 1;
        else swCount1 = 0;
        if (swCount1 == 10) {
            swCount1 = 0;
            // Do something here
            while (readButton(pinButtonTBD) == LOW) delay(1);
        }
        if (readButton(pinButtonThumb) == LOW) swCount2 += 1;
        else swCount2 = 0;
        if (swCount2 == 10) {
            swCount2 = 0;
            isThumbOpen = !isThumbOpen;
            while (readButton(pinButtonThumb) == LOW) delay(1);
        }
        if (readButton(pinButtonOther) == LOW) swCount3 += 1;//A3
        else swCount3 = 0;
        if (swCount3 == 10) {
            swCount3 = 0;
            isOtherLock = !isOtherLock;
            while (readButton(pinButtonOther) == LOW) delay(1);
        }

        sensorValue = readSensor();
        delay(25);
        if(sensorValue<sensorMin) sensorValue=sensorMin;
        else if(sensorValue>sensorMax) sensorValue=sensorMax;
        sensorToPosition();

        outIndex = map(position, positionMin, positionMax, outIndexOpen, outIndexClose);
        servoIndex.write(outIndex);
        if (!isOtherLock){
            outOther = map(position, positionMin, positionMax, outOtherOpen, outOtherClose);
            servoOther.write(outOther);
        }
        if(isThumbOpen) servoThumb.write(outThumbOpen);
        else servoThumb.write(outThumbClose);
        if(onSerial) serialMonitor();
    }
}

/*
* functions
*/
boolean isDigitalPin(const int pin) {
    return (pin >= 0) && (pin <= 19) ? true : false;
}

boolean readButton(const int pin) {
    if ( isDigitalPin(pin) ) {
        return digitalRead(pin);
    } else {
        if (analogRead(pin) > 512) return HIGH;
        else return LOW;
    }
}

int readSensor() {
    int i, sval;
    for (i = 0; i < 10; i++) {
        sval += analogRead(pinSensor);
    }
    sval = sval/10;
    return sval;
}

void sensorToPosition(){
    int tmpVal = map(sensorValue, sensorMin, sensorMax, 100, 0);
    if(tmpVal<thSpeedReverse) speed=speedReverse;
    else if(tmpVal<thSpeedZero) speed=speedMin;
    else speed=map(tmpVal,40,100,speedMin,speedMax);
    position = prePosition + speed;
    if (position < positionMin) position = positionMin;
    if (position > positionMax) position = positionMax;
    prePosition = position;
}

void calibration() {
    outIndex=outIndexOpen;
    servoIndex.write(outIndexOpen);
    servoOther.write(outOtherClose);
    servoThumb.write(outThumbOpen);
    position=positionMin;
    prePosition=positionMin;

    delay(200);
    if(onSerial) Serial.println("======calibration start======");

    sensorMax = readSensor();
    sensorMin = sensorMax - 50;
    unsigned long time = millis();
    while ( millis() < time + 4000 ) {
        sensorValue = readSensor();
        delay(25);
        if ( sensorValue < sensorMin ) sensorMin = sensorValue;
        else if ( sensorValue > sensorMax )sensorMax = sensorValue;

        sensorToPosition();
        outIndex = map(position, positionMin, positionMax, outIndexOpen, outIndexClose);
        servoIndex.write(outIndex);

        if(onSerial) serialMonitor();
    }
    if(onSerial)  Serial.println("======calibration finish======");
    return;
}

void serialMonitor(){
    Serial.print("Min="); Serial.print(sensorMin);
    Serial.print(",Max="); Serial.print(sensorMax);
    Serial.print(",sensor="); Serial.print(sensorValue);
    Serial.print(",speed="); Serial.print(speed);
    Serial.print(",position="); Serial.print(position);
    Serial.print(",outIndex="); Serial.print(outIndex);
    Serial.print(",isThumbOpen="); Serial.print(isThumbOpen);
    Serial.print(",isOtherLock="); Serial.println(isOtherLock);
}

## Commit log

2026-02-05 Track large files with Git LFS
    [C-B-01.stl, C-B-02.stl, C-B-03.stl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]
2026-02-18 added brunel 2.0
    [1st_Finger.stl, 1st_Finger_Distal_001.stl, 1st_Finger_Distal_MOULD.stl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]
2026-03-02 added chestnut PCB
    [1st_Finger.stl, 1st_Finger_Distal_001.stl, 1st_Finger_Distal_MOULD.stl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]

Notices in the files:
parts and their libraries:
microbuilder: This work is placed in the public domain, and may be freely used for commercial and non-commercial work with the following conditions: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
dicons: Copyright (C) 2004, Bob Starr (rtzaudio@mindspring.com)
